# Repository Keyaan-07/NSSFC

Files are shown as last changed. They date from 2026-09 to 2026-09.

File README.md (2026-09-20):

# NSSFC

NSSFC is an FPV flight controller made with the STM32F405 and it has an IMU, Barometric pressure sensor and a magnetometer. It uses the betaflight as firmware(thus no firmware directory in this repository). The package is a typical 37mmx37mm.  

View the board on [KiCanvas](https://kicanvas.org/?repo=https%3A%2F%2Fgithub.com%2FKeyaan-07%2FNSSFC%2Ftree%2Fmain%2Fhardware)  

We made it to learn more about Flight controllers and make PCBs in a small area, especially something like 37x37mm!  

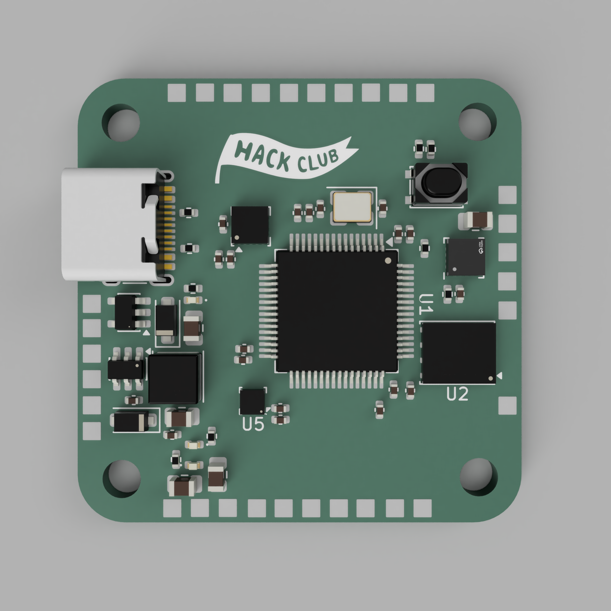
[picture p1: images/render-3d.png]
3d render

pcb
<!-- ![kicad-render](https://cdn.hackclub.com/01a0baac-9bc2-7ff9-bda2-ef1c0acee228/paste-1789838268458.png) -->
kicad render
schematic  

## How to assemble:  
1. Order PCBs and components from the [/hardware/production](/hardware/production/) folder and order them from your supplier and PCB fab. Don't forget to get a stencil along with your PCB!
2. Place the PCB on a flat surface and place the stencil over it. 
3. Use medium-temp solder paste to put the soldermask pattern over the PCB. 
4. Carefully place all the components, use the [ibom](/hardware/bom/ibom.html) for smooth placement. 
5. Solder it in a reflow-oven or a hotplate!
6. You're done!!

## How to flash firmware. 
1. Hold the BOOT0 button and put in the USB into your computer. 
2. Use [betaflight web configurator](https://app.betaflight.com/) to flash the lastest build. [here](https://github.com/betaflight/betaflight/releases/download/2026.6.2/betaflight_2026.6.2_STM32F405.hex) is the latest build!

# BOM
|Designator |Function |Value |Footprint |Quantity|Price |Amount |Link |
|---|---|---|---|---|---|---|---|
|PCB | | | |5 | |2 |https://jlcpcb.com/ |
|Stencil | | | |1 | |3.1 |https://jlcpcb.com/ |
|C1, C16, C2 |Capacitor |2.2u |402 |3 |0.0054 |0.0162 |https://www.lcsc.com/product-detail/C12530.html |
|C10 |Capacitor |1u |402 |1 |0.047 |0.047  |https://www.lcsc.com/product-detail/C1518208.html |
|C11 |Capacitor |4.7u |402 |1 |0.0275 |0.0275 |https://www.lcsc.com/product-detail/C20624278.html|
|C12, C13, C14, C15, C17, C19, C23, C25, C5, C6, C7, C8, C9|Capacitor |100n |402 |13 |0.0045 |0.0585 |https://www.lcsc.com/product-detail/C5182432.html |
|C20 |Capacitor |22u |805 |1 |0.17 |0.17 |https://www.lcsc.com/product-detail/C602037.html  |
|C21, C22, C24 |Capacitor |10u |805 |3 |0.18 |0.54 |https://www.lcsc.com/product-detail/C2932476.html |
|C3, C4 |Capacitor |15p |402 |2 |0.025 |0.05 |https://www.lcsc.com/product-detail/C441742.html  |
|D1, D2 |Diode |D_Schottky |D_SOD-123F |2 |0.035 |0.07 |https://www.lcsc.com/product-detail/C432153.html  |
|D3, D4, D5 |LED |LED |402 |3 |0.054 |0.162  |https://www.lcsc.com/product-detail/C2980183.html |
|J1 |USB C receptacle|USB_C_Receptacle|USB_C_Receptacle_XKB_U262-16XN-4BVC11 |1 |0.059 |0.059  |https://www.lcsc.com/product-detail/C393939.html  |
|L1 |Inductor |4.7u |L_Changjiang_FNR4020S |1 |0.082 |0.082  |https://www.lcsc.com/product-detail/C167828.html  |
|R1, R6 |Resistor |10k |402 |2 |0.0425 |0.085  |https://www.lcsc.com/product-detail/C3020235.html |
|R2, R3 |Resistor |4.7k |402 |2 |0.0026 |0.0052 |https://www.lcsc.com/product-detail/C25900.html |
|R4, R5 |Resistor |5.1k |402 |2 |0.006 |0.012  |https://www.lcsc.com/product-detail/C278598.html  |
|R7 |Resistor |1k |402 |1 |0.066 |0.066  |https://www.lcsc.com/product-detail/C427241.html  |
|R8 |Resistor |220 |402 |1 |0.002 |0.002  |https://www.lcsc.com/product-detail/C2909336.html |
|R9 |Resistor |100 |402 |1 |0.026 |0.026  |https://www.lcsc.com/product-detail/C427204.html  |
|SW1 |Push button |SW_Push |SW_SPST_PTS810 |1 |0.3425 |0.3425 |https://www.lcsc.com/product-detail/C221895.html  |
|U1 |MCU |STM32F405RGTx |LQFP-64_10x10mm_P0.5mm |1 |6.01 |6.01 |https://www.lcsc.com/product-detail/C15742.html |
|U2 |Flash |W25Q128JVP |WSON-8-1EP_6x5mm_P1.27mm_EP3.4x4.3mm |1 |2.82 |2.82 |https://www.lcsc.com/product-detail/C2441427.html |
|U3 |magnetometer |QMC5883P |LGA-16_3x3_Pitch0.5mm_QMC5883P |1 |1.57 |1.57 |https://www.lcsc.com/product-detail/C2847467.html |
|U4 |IMU |ICM-20602 |LGA-16_3x3mm_P0.5mm_LayoutBorder3x5y |1 |6.02 |6.02 |https://www.lcsc.com/product-detail/C97633.html |
|U5 |Pressure Sensor |BMP580 |ST_HLGA-10_2x2mm_P0.5mm_LayoutBorder3x2y|1 |1.21 |1.21 |https://www.lcsc.com/product-detail/C22391138.html|
|U6 |Buck |AP63205WU |TSOT-23-6 |1 |0.43 |0.43 |https://www.lcsc.com/product-detail/C2071056.html |
|U7 |LDO |TLV75733PDBV |SOT-23-5 |1 |0.2 |0.2 |https://www.lcsc.com/product-detail/C485517.html  |
|Y1 |Crystals |25MHz |Crystal_SMD_3225-4Pin_3.2x2.5mm |1 |0.1 |0.1 |https://www.lcsc.com/product-detail/C70582.html |
| | | | | |LCSC shipping|9.3 | |
| | | | | |PCB Shipping |11.25  | |
| | | | | |Total |45.8309| |

Made by Keyaan and Ahad

# Licensing
Licensed under the MIT License!

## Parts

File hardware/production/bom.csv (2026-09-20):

Designator | Footprint | Value | Quantity | Price | Link
C1, C16, C2 | 402 | 2.2u | 50 | 0.39 | https://www.lcsc.com/product-detail/C18164601.html
C10 | 402 | 1u | 100 | 0.27 | https://www.lcsc.com/product-detail/C53308526.html
C11 | 805 | 4.7u | 20 | 0.42 | https://www.lcsc.com/product-detail/C84718.html
C12, C13, C14, C15, C17, C19, C23, C25, C5, C6, C7, C8, C9 | 402 | 100n | 100 | 0.46 | https://www.lcsc.com/product-detail/C1525.html
C20 | 805 | 22u | 20 | 0.52 | https://www.lcsc.com/product-detail/C49326686.html
C21, C22, C24 | 805 | 10u | 20 | 1.27 | https://www.lcsc.com/product-detail/C1713.html
C3, C4 | 402 | 15p | 100 | 0.73 | https://www.lcsc.com/product-detail/C1852854.html
D1, D2 | D_SOD-123F | D_Schottky | 20 | 0.7 | https://www.lcsc.com/product-detail/C5140024.html
D3, D4, D5 | 402 | LED | 100 | 0.59 | https://www.lcsc.com/product-detail/C19273151.html?s_z=n_q_t_led
J1 | USB_C_Receptacle_XKB_U262-16XN-4BVC11 | USB_C_Receptacle_USB2.0_16P | 10 | 0.63 | https://www.lcsc.com/product-detail/C54829816.html
L1 | L_Changjiang_FNR4020S | 4.7u | 5 | 0.43 | https://www.lcsc.com/product-detail/C128692.html
R1, R6 | 402 | 10k | 100 | 0.29 | https://www.lcsc.com/product-detail/C2906885.html
R2, R3 | 402 | 4.7k | 100 | 0.13 | https://www.lcsc.com/product-detail/C48392572.html
R4, R5 | 402 | 5.1k | 100 | 0.11 | https://www.lcsc.com/product-detail/C453708.html
R7 | 402 | 1k | 100 | 0.19 | https://www.lcsc.com/product-detail/C2906899.html
R8 | 402 | 220 | 100 | 0.18 | https://www.lcsc.com/product-detail/C2906912.html
R9 | 402 | 100 | 100 | 0.17 | https://www.lcsc.com/product-detail/C2906860.html
SW1 | SW_SPST_PTS810 | SW_Push | 5 | 1.71 | https://www.lcsc.com/product-detail/C221895.html?s_z=n_q_pts810
U1 | LQFP-64_10x10mm_P0.5mm | STM32F405RGTx | 3 | 18.04 | https://www.lcsc.com/product-detail/C15742.html?s_z=n_q_STM32F405RGT
U2 | WSON-8-1EP_6x5mm_P1.27mm_EP3.4x4.3mm | W25Q128JVP | 3 | 2.32 | https://www.lcsc.com/product-detail/C2641199.html?s_z=n_q_W25Q128JVP
U3 | LGA-16_3x3_Pitch0.5mm_QMC5883P | QMC5883P | 3 | 4.32 | https://www.lcsc.com/product-detail/C2847467.html?s_z=n_q_QMC5883P
U4 | LGA-16_3x3mm_P0.5mm_LayoutBorder3x5y | ICM-20602 | 3 | 18.07 | https://www.lcsc.com/product-detail/C97633.html
U5 | ST_HLGA-10_2x2mm_P0.5mm_LayoutBorder3x2y | BMP580 | 3 | 3.64 | https://www.lcsc.com/product-detail/C22391138.html
U6 | TSOT-23-6 | AP63205WU | 3 | 1.27 | https://www.lcsc.com/product-detail/C2071056.html
U7 | SOT-23-5 | TLV75733PDBV | 5 | 0.59 | https://www.lcsc.com/product-detail/C54539933.html?s_z=n_q_TLV75733PDBV
Y1 | Crystal_SMD_3225-4Pin_3.2x2.5mm | 25MHz | 5 | 0.48 | https://www.lcsc.com/product-detail/C9006.html
 |  |  | PCB | 9.74
 |  |  | Shipping | 8.77
 |  |  | Total | 76.43

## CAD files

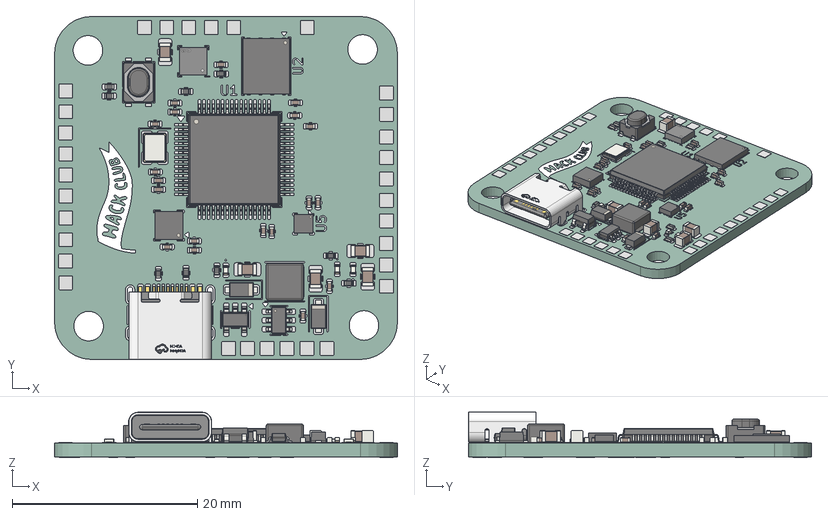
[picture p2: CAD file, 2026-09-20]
3d/nssfc.step
37.0 x 37.0 x 4.92 mm
C_0402_1005Metric x 19
Crystal_SMD_3225-4Pin_3.2x2.5mm
C_0805_2012Metric x 5
R_0402_1005Metric x 9
ST_HLGA-10_2x2mm_P0.5mm_LayoutBorder3x2y
WSON-8-1EP_6x5mm_P1.27mm_EP3.4x4.3mm
LED_0402_1005Metric x 3
SOT-23-5
D_SOD_123F x 2
USB-C-SMD_TYPE-C16PIN
LQFP-64_10x10mm_P0.5mm
LGA_16_3x3mm_P05mm_LayoutBorder3x5y
LGA-16_L3.0-W3.0-H0.9-P0.50
L_Changjiang_FNR4020S
SW_SPST_PTS810
TSOT-23-6
nssfc_pad
nssfc_silkscreen x 2
nssfc_PCB

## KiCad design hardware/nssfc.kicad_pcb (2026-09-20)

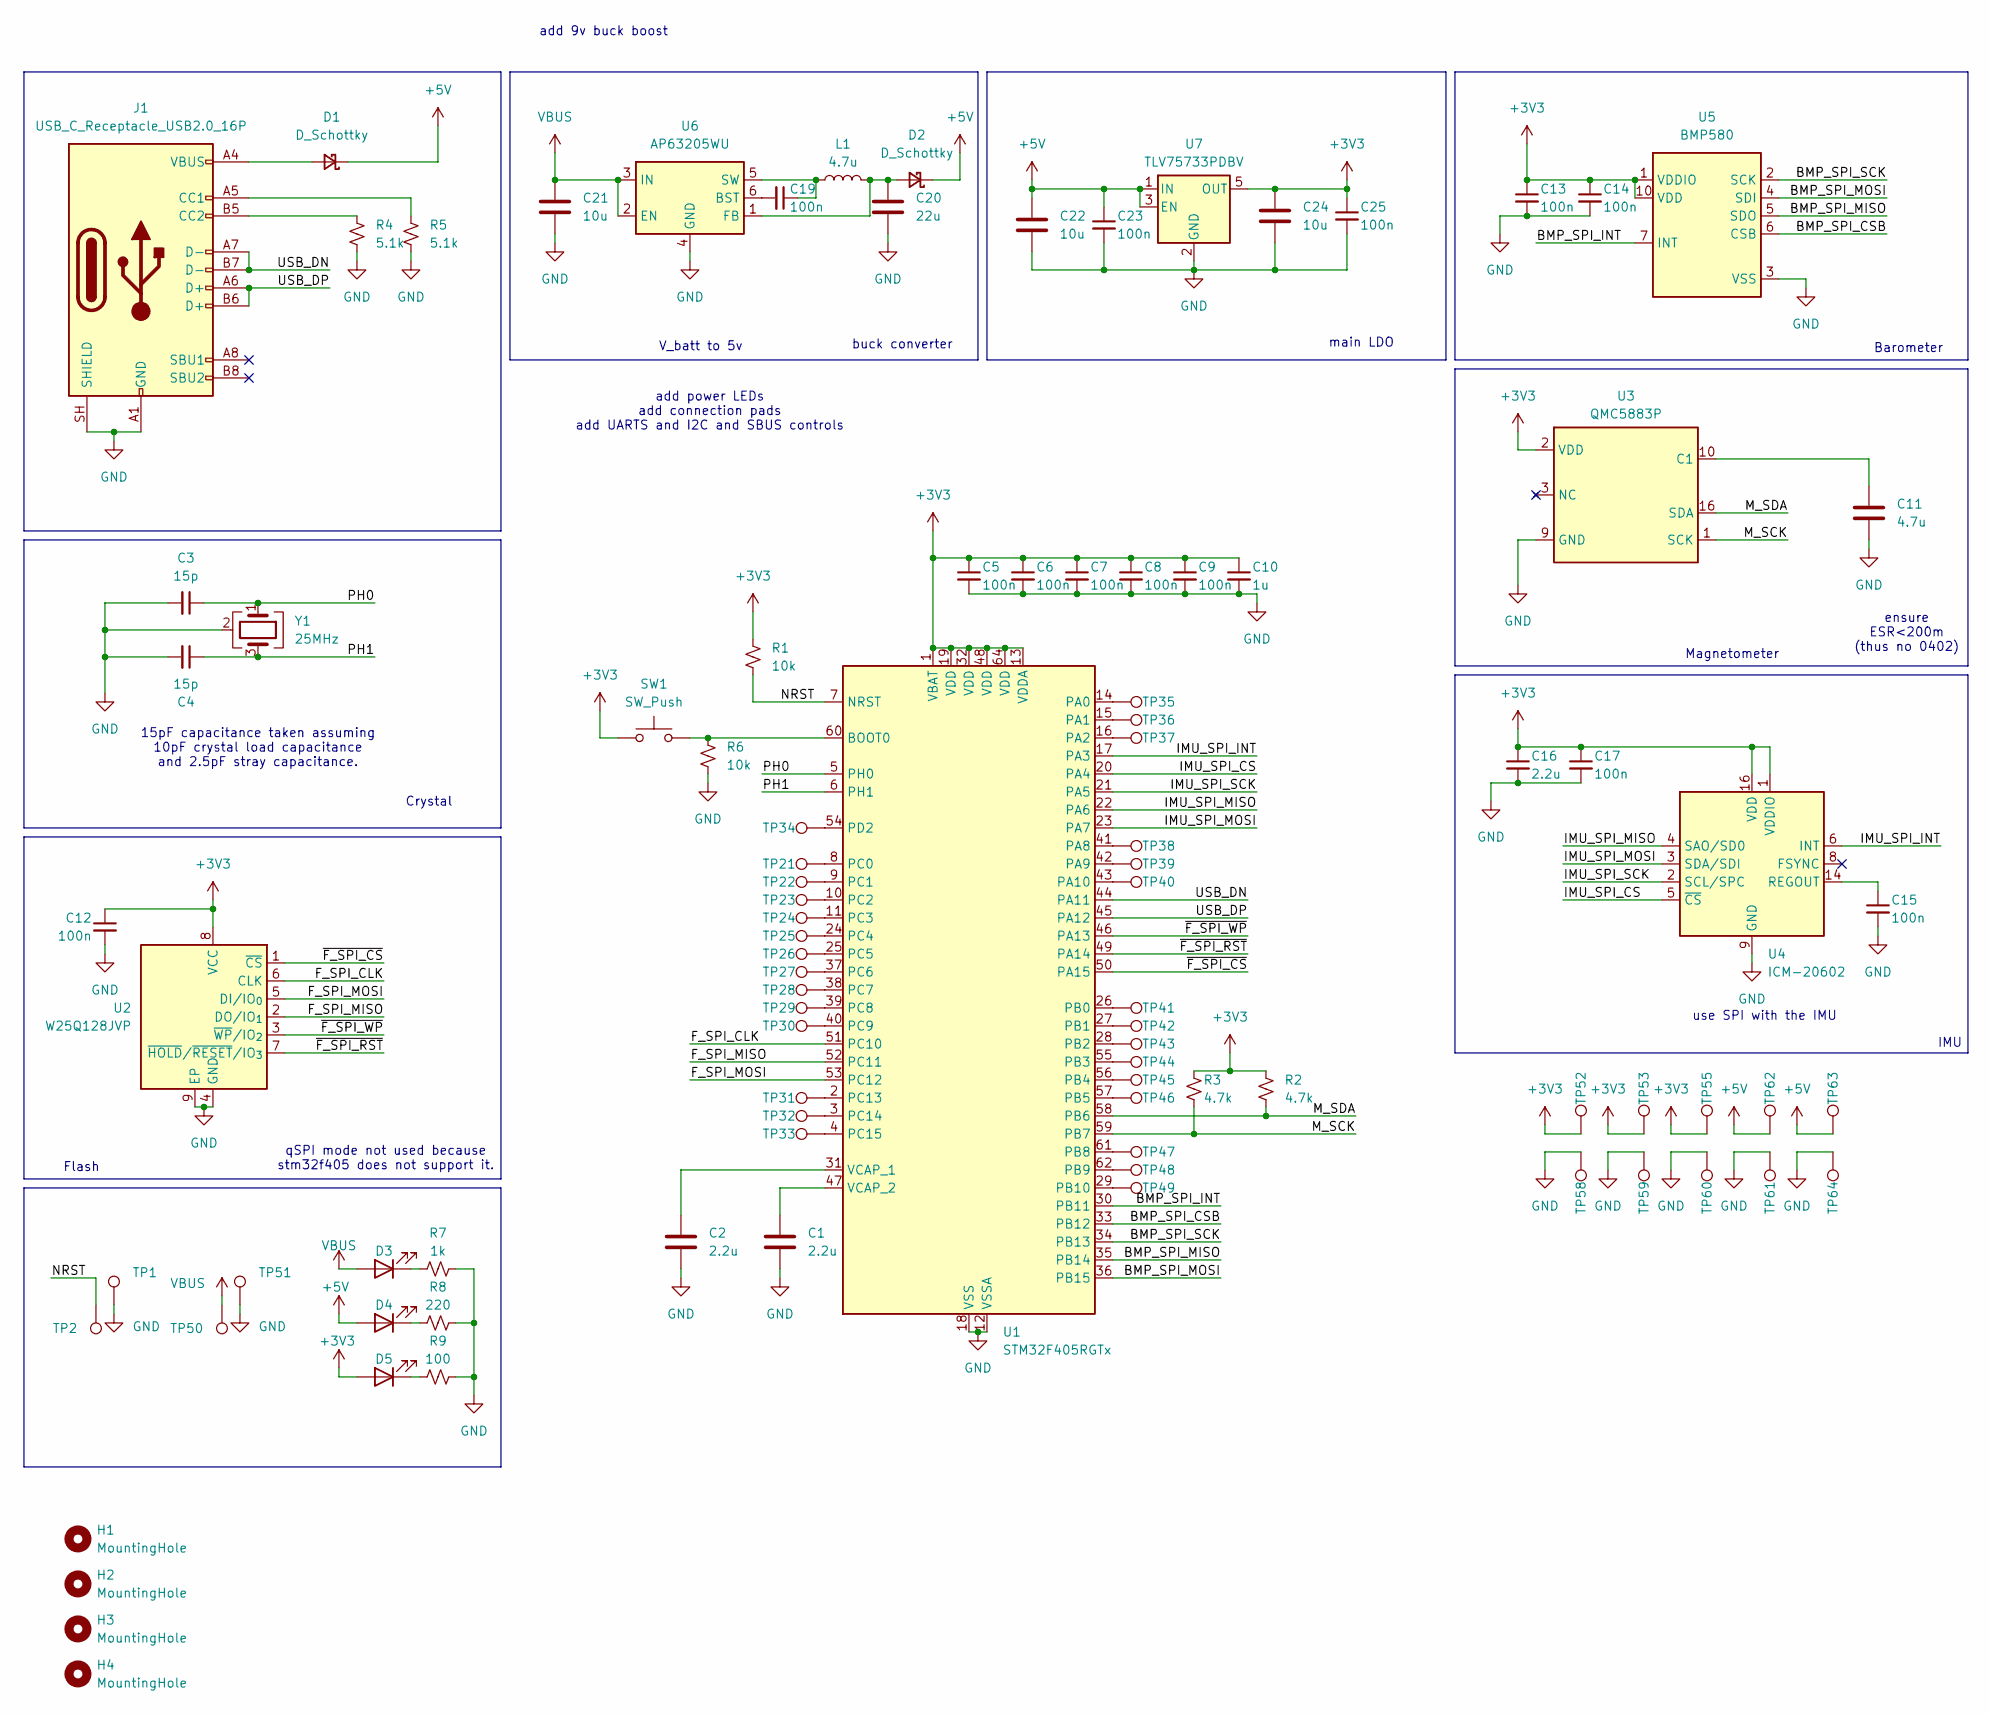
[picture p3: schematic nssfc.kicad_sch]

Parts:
C1, C2, C16: 2.2u; C_0402_1005Metric
C3, C4: 15p; C_0402_1005Metric
C5, C6, C7, C8, C9, C12, C13, C14, C15, C17, C19, C23, C25: 100n; C_0402_1005Metric
C10: 1u; C_0402_1005Metric
C11: 4.7u; C_0805_2012Metric
C20: 22u; C_0805_2012Metric
C21, C22, C24: 10u; C_0805_2012Metric
D1, D2: D_Schottky; D_SOD-123F
D3, D4, D5: LED; LED_0402_1005Metric
H1, H2, H3, H4: MountingHole; MountingHole_3.2mm_M3
J1: USB_C_Receptacle_USB2.0_16P; USB_C_Receptacle_XKB_U262-16XN-4BVC11
L1: 4.7u; L_Changjiang_FNR4020S
R1, R6: 10k; R_0402_1005Metric
R2, R3: 4.7k; R_0402_1005Metric
R4, R5: 5.1k; R_0402_1005Metric
R7: 1k; R_0402_1005Metric
R8: 220; R_0402_1005Metric
R9: 100; R_0402_1005Metric
SW1: SW_Push; SW_SPST_PTS810
TP1, TP2: TestPoint; TestPoint_Pad_1.0x1.0mm
TP21, TP22, TP23, TP24, TP25, TP26, TP27, TP28, TP29, TP30, TP31, TP32, TP33, TP34, TP35, TP36, TP37, TP38, TP39, TP40, TP41, TP42, TP43, TP44, TP45, TP46, TP47, TP48, TP49, TP52, TP53, TP55, TP58, TP59, TP60, TP61, TP62, TP63, TP64: TestPoint; PAD_1.5mm
TP50, TP51: TestPoint; TestPoint_Pad_2.0x2.0mm
U1: STM32F405RGTx; LQFP-64_10x10mm_P0.5mm
U2: W25Q128JVP; WSON-8-1EP_6x5mm_P1.27mm_EP3.4x4.3mm
U3: QMC5883P; LGA-16_3x3_Pitch0.5mm_QMC5883P
U4: ICM-20602; LGA-16_3x3mm_P0.5mm_LayoutBorder3x5y
U5: BMP580; ST_HLGA-10_2x2mm_P0.5mm_LayoutBorder3x2y
U6: AP63205WU; TSOT-23-6
U7: TLV75733PDBV; SOT-23-5
Y1: 25MHz; Crystal_SMD_3225-4Pin_3.2x2.5mm

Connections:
+3V3: C5.1, C6.1, C7.1, C8.1, C9.1, C10.1, C12.1, C13.1, C14.1, C16.1, C17.1, C24.1, C25.1, D5.2 (A), R1.1, R2.1, R3.1, SW1.1, TP52.1 (1_1), TP53.1 (1_1), TP55.1 (1_1), U1.1 (VBAT), U1.13 (VDDA), U1.19 (VDD), U1.32 (VDD), U1.48 (VDD), U1.64 (VDD), U2.8 (VCC), U3.2 (VDD), U4.1 (VDDIO), U4.16 (VDD), U5.1 (VDDIO), U5.10 (VDD), U7.5 (OUT)
+5V: C22.1, C23.1, D1.1 (K), D2.1 (K), D4.2 (A), TP62.1 (1_1), TP63.1 (1_1), U7.1 (IN), U7.3 (EN)
/BMP_SPI_CSB: U1.33 (PB12), U5.6 (CSB)
/BMP_SPI_INT: U1.30 (PB11), U5.7 (INT)
/BMP_SPI_MISO: U1.35 (PB14), U5.5 (SDO)
/BMP_SPI_MOSI: U1.36 (PB15), U5.4 (SDI)
/BMP_SPI_SCK: U1.34 (PB13), U5.2 (SCK)
/F_SPI_CLK: U1.51 (PC10), U2.6 (CLK)
/F_SPI_MISO: U1.52 (PC11), U2.2 (DO/IO_{1})
/F_SPI_MOSI: U1.53 (PC12), U2.5 (DI/IO_{0})
/IMU_SPI_CS: U1.20 (PA4), U4.5 (~CS)
/IMU_SPI_INT: U1.17 (PA3), U4.6 (INT)
/IMU_SPI_MISO: U1.22 (PA6), U4.4 (SAO/SD0)
/IMU_SPI_MOSI: U1.23 (PA7), U4.3 (SDA/SDI)
/IMU_SPI_SCK: U1.21 (PA5), U4.2 (SCL/SPC)
/M_SCK: R3.2, U1.59 (PB7), U3.1 (SCK)
/M_SDA: R2.2, U1.58 (PB6), U3.16 (SDA)
/NRST: R1.2, TP2.1 (1_1), U1.7 (NRST)
/PH0: C3.1, U1.5 (PH0), Y1.1
/PH1: C4.1, U1.6 (PH1), Y1.3
/USB_DN: J1.A7 (D-), J1.B7 (D-), U1.44 (PA11)
/USB_DP: J1.A6 (D+), J1.B6 (D+), U1.45 (PA12)
/~F_SPI_CS: U1.50 (PA15), U2.1 (~CS)
/~F_SPI_RST: U1.49 (PA14), U2.7 (~HOLD/~RESET/IO_{3})
/~F_SPI_WP: U1.46 (PA13), U2.3 (~WP/IO_{2})
GND: C1.2, C2.2, C3.2, C4.2, C5.2, C6.2, C7.2, C8.2, C9.2, C10.2, C11.2, C12.2, C13.2, C14.2, C15.2, C16.2, C17.2, C20.2, C21.2, C22.2, C23.2, C24.2, C25.2, J1.A1 (GND), J1.A12 (GND), J1.B1 (GND), J1.B12 (GND), J1.SH (SHIELD), R4.2, R5.2, R6.2, R7.2, R8.2, R9.2, TP1.1 (1_1), TP51.1 (1_1), TP58.1 (1_1), TP59.1 (1_1), TP60.1 (1_1), TP61.1 (1_1), TP64.1 (1_1), U1.12 (VSSA), U1.18 (VSS), U1.63 (VSS), U2.4 (GND), U2.9 (EP), U3.9 (GND), U3.11 (GND), U4.9 (GND), U4.10 (GND), U4.11 (GND), U4.12 (GND), U4.13 (GND), U4.15 (GND), U5.3 (VSS), U5.8 (VSS), U5.9 (VSS), U6.4 (GND), U7.2 (GND), Y1.2 (G), Y1.4 (G)
unnamed: D1.2 (A), J1.A4 (VBUS), J1.A9 (VBUS), J1.B4 (VBUS), J1.B9 (VBUS)
unnamed: C20.1, D2.2 (A), L1.2, U6.1 (FB)
unnamed: D3.1 (K), R7.1
unnamed: D4.1 (K), R8.1
unnamed: D5.1 (K), R9.1
unnamed: J1.A5 (CC1), R5.1
unnamed: J1.B5 (CC2), R4.1
unnamed: R6.1, SW1.2, U1.60 (BOOT0)
unnamed: TP35.1 (1_1), U1.14 (PA0)
unnamed: TP36.1 (1_1), U1.15 (PA1)
unnamed: TP37.1 (1_1), U1.16 (PA2)
unnamed: TP38.1 (1_1), U1.41 (PA8)
unnamed: TP39.1 (1_1), U1.42 (PA9)
unnamed: TP40.1 (1_1), U1.43 (PA10)
unnamed: TP41.1 (1_1), U1.26 (PB0)
unnamed: TP42.1 (1_1), U1.27 (PB1)
unnamed: TP43.1 (1_1), U1.28 (PB2)
unnamed: TP44.1 (1_1), U1.55 (PB3)
unnamed: TP45.1 (1_1), U1.56 (PB4)
unnamed: TP46.1 (1_1), U1.57 (PB5)
unnamed: TP47.1 (1_1), U1.61 (PB8)
unnamed: TP48.1 (1_1), U1.62 (PB9)
unnamed: TP49.1 (1_1), U1.29 (PB10)
unnamed: TP21.1 (1_1), U1.8 (PC0)
unnamed: TP22.1 (1_1), U1.9 (PC1)
unnamed: TP23.1 (1_1), U1.10 (PC2)
unnamed: TP24.1 (1_1), U1.11 (PC3)
unnamed: TP25.1 (1_1), U1.24 (PC4)
unnamed: TP26.1 (1_1), U1.25 (PC5)
unnamed: TP27.1 (1_1), U1.37 (PC6)
unnamed: TP28.1 (1_1), U1.38 (PC7)
unnamed: TP29.1 (1_1), U1.39 (PC8)
unnamed: TP30.1 (1_1), U1.40 (PC9)
unnamed: TP31.1 (1_1), U1.2 (PC13)
unnamed: TP32.1 (1_1), U1.3 (PC14)
unnamed: TP33.1 (1_1), U1.4 (PC15)
unnamed: TP34.1 (1_1), U1.54 (PD2)
unnamed: C2.1, U1.31 (VCAP_1)
unnamed: C1.1, U1.47 (VCAP_2)
unnamed: C11.1, U3.10 (C1)
unnamed: C15.1, U4.14 (REGOUT)
unnamed: C19.2, U6.6 (BST)
unnamed: C19.1, L1.1, U6.5 (SW)
VBUS: C21.1, D3.2 (A), TP50.1 (1_1), U6.2 (EN), U6.3 (IN)

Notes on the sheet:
add power LEDs add connection pads add UARTS and I2C and SBUS controls
main LDO
Flash
qSPI mode not used because stm32f405 does not support it.
15pF capacitance taken assuming 10pF crystal load capacitance and 2.5pF stray capacitance.
add 9v buck boost
ensure ESR<200m (thus no 0402)
IMU
Crystal
V_batt to 5v
buck converter
Barometer
Magnetometer
use SPI with the IMU

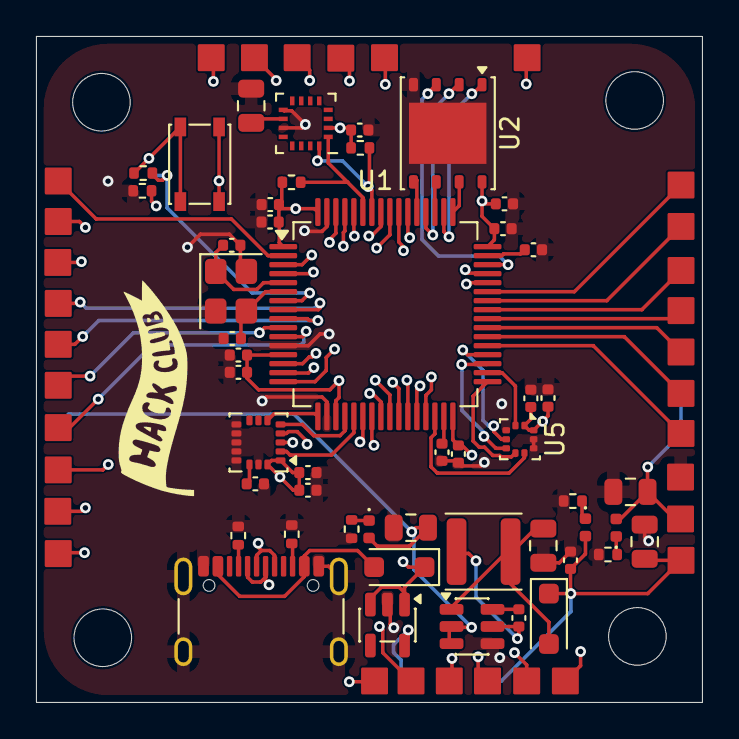
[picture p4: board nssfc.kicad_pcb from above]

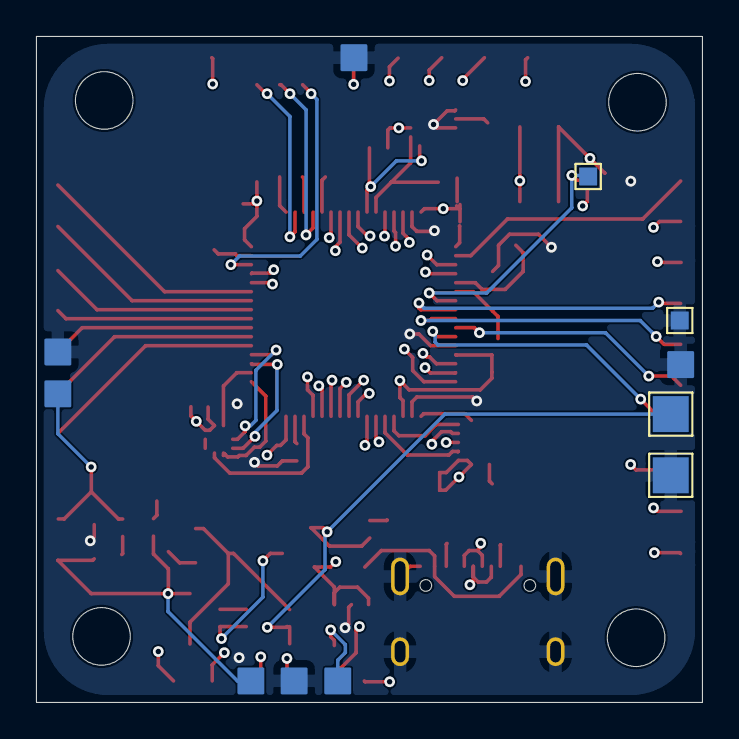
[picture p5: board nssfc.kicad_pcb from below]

Board: 4 copper layers, 37.0 x 37.0 mm, 96 parts (11 on the bottom side), 70 nets.

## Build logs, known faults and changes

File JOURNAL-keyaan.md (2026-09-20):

# 14 sept 2026
Today is the first day for third-space, and i am starting this project, i am really exceited to build a flight controller and coordinate different sensors!

I lowkey wanna make it look like those traditional flight controllers that you see on FPV drones, and i will try my best to make it look like that! Here's how i began:  

I set up my image paste CDN plugin by qcoral as it is amazing!
First and foremost, i began by putting two capacitors to the VCAP_1 and VCAP_2 pins, which connect to internal voltages and provide decoupling, and it is important that one must not connect anything else to them:  
  

I added a crystal by reading the datasheet, and i've decided that i'll probably use a 10pF crystal:  
  

added decoupling caps too!  


I feel like the W25Q128JVP is a goated flash IC, not just because it has good amount of storage, but the package is so awesome too, and it satisfies all my requirements, thus i chose 25q128jvp with a wSON package. 

I also worked on some minor stuff, such as pull up to the reset, and adding a note to the future for adding a button:  
  

Okay so the magnetometer i decided on is called the QMC5883P and is supported by betaflight(yes i think this is a good time to tell i am leaning towards betaflight firmware!), and thus i went with it. There was no default symbol or footprint for the LGA, thus i had to make it myself, they can be located in /hardware/nssfc.pretty and /harwdare/nssfc.kicad_sym which were created by me!



Oh btw i chose BMP580 for the pressure sensor, because it is not that expensive and gets the work done perfectly, there was no symbol for this as well, and i made my own, tho the footprint was there:  

That is all for this session, time spent: 1 hour 46 mins

# 15 sept 2026

I worked on the schematic today, after ahad. and i think i am done with the schematic. did a lot of stuff today, so here is it:  

completed work on all 3 sensors:  
  
  
made the buck converter and the LDO:  
  
worked on the USB Port:  
  
main MCU looks like this:  
  
now the only part left out is a buck-boost IC for the VTX port, and probably a uSD card slot(tho we'll probably not add it)  
I assigned all the footprints as well, and i have not yet found an inductor so i did not add that footprint. For the schottky diodes, i have added [this](https://www.lcsc.com/product-detail/Schottky-Barrier-Diodes-SBD_LGE_C432153.html) diode's footprint. 
Did a bit of placement of the PCB, here is how it looks:  
  
I found a footprint for the inductor, here it is:  
  
okay so i am done with the project for the day, and i am exhausted, so here is the final pic:  
  
  

# 16 sept 2026

i did a part of the placement of the board, and i think that we'll be done with less than 10 hours each sob. This is what the board looks like right now:  


# 18 sept 2026

I have been given the placement task by ahad, as he says he is bad at placement, thus i'll take my time out today and complete the placement! Here is progress 30 mins in the session:  
  
Me tryna make it look like a commercial FPV drone flight controller!!  

I did some footprint manipulation for easier routing for my IMU circuitry, and i have informed ahad to do the same too. Here is the updated footprint:  
  

I removed the two pins on the bottom right. The actual routing will be done like this:  
  

Oh also, i dont know if i have told it, but i have made these pads myself :3c  
  

I am done with the placement and some routing, and it looks beautiful:  


# 19 sept 2026
i did some routing fixes, and this is what the PCB looks like in one type of view, so amazing:  
  
Okay so now everything is done, here is how the final PCB looks:  
  
  
Now time for rendering!!

# 20 september 2026
It is a few hours before midnight, and i am doing final renders, because ahad had to re-route his PCB for some reason. Thus, i have to do a new render for the README images, thus me doing that.  

Time spent: about 30 minutes.

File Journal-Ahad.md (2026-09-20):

# 15 September 2026
I have done some part of the schematic in which i did the wiring of the ICM-20206 and the BMP580. Which i did by finding the pin number in the datasheet double checking it and finally connecting it using labels, i checked what the pin does 2 times so my partner doesn't get any problems while doing his work. Also i was AFK for 2-3 minutes which i was talking to my partner.





# 16 & 17 September 2026

I worked on the layout which was mostly done by my partner. I forgot to save my work last time and my laptop died :sob: which was about 30 mins of work which i did rn. The routing must be bad compared to my teammate as he has benn working on hardware for like 5 years and i am not even 5 months in so he might reroute a few things and i will also do the main thing that is the connection pads for connecting all the stuff. I was talking to my teammate for about 5 to 10 mins so i might be AFK in the lapse




# 17 September 2026

i added the pads which were the time taking part as i was not able to fit into the previous layout so i had to do the layout again which was mostly done by me and my teammate also helped me in finding the corect footprint. I also added the testpoints in the schematic which i found confusing



# 19 September 2026

I had started routing the PCB after routing it 3 times and phew that wa s brutal torture after seeing the first one that I layed out and routed myself. My teammate helped in the layout or else i would have to take several hits from #hardware in slack. Finally our project is ready (hopefully) and only the parts of repo are remaining. I did not rely on my teammate




# 20 September 2026

i rerouted the PCB again as i forgot to add the mounting holes and didnt have space to add them so i fully deleted the PCB and started it again this time not forgetting the mounting holes. And finally our PCB and the Full Flight controller is ready. And we got to learn so much from this and it was so fun rerouting iy like a thousand times.





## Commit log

2026-09-14 hello world
    [nssfc.kicad_pcb, nssfc.kicad_sch]
2026-09-14 made the schematic
    [nssfc.kicad_pcb, nssfc.kicad_sch]
2026-09-15 saved the repository
    [nssfc.kicad_pcb, nssfc.kicad_sch]
2026-09-15 saving the repository
    [nssfc.kicad_pcb, nssfc.kicad_sch]
2026-09-15 worked on the schematic
    [nssfc.kicad_pcb, nssfc.kicad_sch]
2026-09-16 worked on PCB layout
    [nssfc.kicad_pcb, nssfc.kicad_sch]
2026-09-17 completed PCB
    [nssfc.kicad_pcb]
2026-09-18 layout change in PCB
    [nssfc.kicad_pcb, nssfc.kicad_sch]
2026-09-18 rerouted PCB
    [nssfc.kicad_pcb]
2026-09-18 placement session: i am locked in
    [nssfc.kicad_pcb, nssfc.kicad_sch]
2026-09-18 completed placement
    [nssfc.kicad_pcb, nssfc.kicad_sch]
2026-09-19 changed PCB
    [nssfc.kicad_pcb]
2026-09-19 done PCB
    [bom.csv, designators.csv, nssfc.kicad_pcb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]
2026-09-19 added BOM
    [bom.csv]
2026-09-19 fusion rendering
    [nssfc.kicad_pcb]
2026-09-19 schematic with background colour added
